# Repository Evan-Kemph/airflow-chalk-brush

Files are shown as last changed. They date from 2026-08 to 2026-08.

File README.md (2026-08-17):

# Airflow Chalk Brush

A handheld, rechargeable brush for cleaning chalk off climbing holds. A small motor and impeller blow air out a nozzle right at the bristles, so loosened chalk gets carried away instead of resettling into the texture of the hold.

Designed to be cheap, easy to assemble, and fully 3D printable apart from a short list of off-the-shelf parts. Everything here is free to use, modify, and remix.

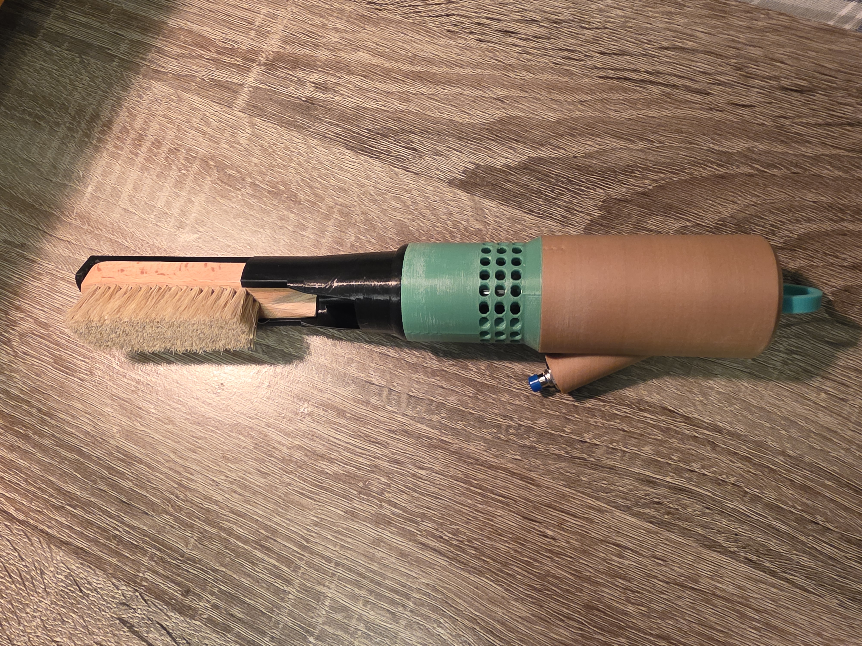
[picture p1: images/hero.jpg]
The finished brush


---

## Contents

- [What it does](#what-it-does)
- [How it works](#how-it-works)
- [Bill of materials](#bill-of-materials)
- [Printed parts](#printed-parts)
- [Print settings](#print-settings)
- [Support placement](#support-placement)
- [Assembly](#assembly)
- [Using it](#using-it)
- [Design notes](#design-notes)
- [Troubleshooting](#troubleshooting)
- [Remixing this design](#remixing-this-design)
- [Safety](#safety)
- [License](#license)

---

## What it does

Brushing a climbing hold knocks chalk loose, but a lot of it just settles back into the surface. This brush adds a burst of air at the bristle line so the chalk you loosen actually leaves the hold.

The body is a threaded tube that stacks from the bottom up:

| Section | Contains |
|---|---|
| **Bottom** | LiPo battery, USB-C charging board, button, integrated carabiner clip |
| **USB board spacer** | Braces the charging board so plugging in a cable can't push it inward |
| **Motor mount** | Holds the motor; routes the motor wires *downward* into the bottom section |
| **Middle (hilt)** | Impeller chamber and air intakes |
| **Head** | Air channel, exit nozzle, and brush mount |

The main sections screw together with printed threads, so the brush fully disassembles for battery access or repair — no glue holding the body together.

One design decision worth explaining: the motor mount sits *between* the bottom and middle sections specifically so the motor's wires exit downward rather than upward. That puts every electrical component — battery, charging board, button, and both motor leads — inside the bottom section, which means **the entire circuit is soldered as one piece with no connectors anywhere.** Fewer parts, nothing to work loose, and nothing to accidentally unplug when you unscrew the brush.

Press and hold the button to run the motor. Release to stop. Charge over USB-C.

---

## How it works

Air is drawn in through intake holes in the middle section, pushed up past the impeller, and forced through a narrowing channel to a nozzle that exits at the base of the bristles.

The interesting engineering problem here is that a small axial fan is a **high-flow, low-pressure** device. It moves a lot of air when the path is open, but it stalls badly against a restriction. Early versions of this design had a nozzle that was too small, and instead of blowing air out the front, the fan simply recirculated it back out the intake holes — a lot of noise and no useful airflow.

The final design solves this by keeping total flow restriction low: a generously sized exit, a smooth gradual taper rather than an abrupt contraction, rounded rather than sharp-edged openings, and a tight impeller tip clearance so air doesn't leak backwards around the blades.

More detail in [Design notes](#design-notes).

---

## Bill of materials

> **Affiliate disclosure: I do not profit from any of these links.** They aren't affiliate links and I receive nothing if you buy through them. They're simply the exact parts I bought, linked so you can match what the model was designed around. Buy them anywhere you like.

| Part | Qty | Notes | Link |
|---|---|---|---|
| Coreless motor, 8520 (8.5 × 20 mm), 3.7 V | 1 | 1 mm shaft. Sold as micro-drone spares, usually in pairs. | https://www.amazon.com/dp/B07CPT5TSL?ref_=ppx_hzsearch_conn_dt_b_fed_asin_title_1 |
| 1S LiPo battery, 3.7 V | 1 | 2100mAh. Must physically fit the bottom section. | https://www.amazon.com/dp/B091YKTT9S?ref=ppx_yo2ov_dt_b_fed_asin_title |
| TP4056 USB-C charging module **with protection** | 1 | Get the 3-chip version (TP4056 + DW01A + FS8205). The 2-chip version has no battery protection. | https://www.amazon.com/dp/B07PKND8KG?ref_=ppx_hzsearch_conn_dt_b_fed_asin_title_3 |
| Momentary pushbutton, 12 mm | 1 | Rated 3 A or better. Panel-mounts through the printed hole. | amazon.com/dp/B07RTZVZ6L?ref_=ppx_hzsearch_conn_dt_b_fed_asin_title_4 |
|switch|1|switch to turn on and off circuit, as to prevent it from turning on in a gym bag|https://www.amazon.com/dp/B09R43HCY3?ref_=ppx_hzsearch_conn_dt_b_fed_asin_title_4&th=1|
| Series resistor | 1 | ~1 ohm. See [Troubleshooting](#troubleshooting) for why this is here. | any |
| Wooden brush head | 1 | Cut flat 20mm below the bottom bristles and make an indent (see photos) | https://www.amazon.com/dp/B08XKM8LL2?ref_=ppx_hzsearch_conn_dt_b_fed_asin_title_2 |
| Silicone wire, 22–24 AWG | — | Short lengths, red and black. | https://www.amazon.com/dp/B07TX6BX47?ref=ppx_yo2ov_dt_b_fed_asin_title&th=1 |
| Heat shrink tubing | — | Assorted small sizes. | — |

**Approximate total cost: cheaper than buying the stupid overpriced one I saw on Instagram**

Most items come in multi-packs, so the per-unit cost is lower if you build more than one.

### Substitutions

The design is not fussy about brands, but a few things do matter:

- **The charging board must have battery protection.** Boards without it will let a LiPo over-discharge, which ruins the cell and is a genuine fire risk.
- **The battery must be a single cell (1S / 3.7 V).** A 2S pack will destroy the motor and is not compatible with this charging board.
- **The motor must be rated for 3.7 V.** Many similar-looking motors are 6 V or 12 V and will barely turn on a 1S cell.

---

## Printed parts

Seven files, six required and one optional. Numbered in assembly order.

| # | File | Qty | Description |
|---|---|---|---|
| 1 | `bottom.stl` | 1 | Battery compartment, USB-C port opening, button hole, integrated carabiner clip |
| 2 | `usb-board-spacer.stl` | 1 | Sits between the bottom and the motor mount. Braces the charging board from behind so plugging in a USB cable can't push it out of position — this removes the need to glue the board in. |
| 3 | `motor-mount.stl` | 1 | Holds the motor. Sits between the bottom and middle sections, with a pass-through for the motor wires to route down into the bottom. |
| 4 | `middle-hilt.stl` | 1 | Impeller chamber and air intakes |
| 5 | `head.stl` | 1 | Air channel, exit nozzle, and brush mount |
| 6 | `switch-clip.stl` | 1 | Retains the button and prevents accidental activation in a bag or on a harness. hold in the switch so it does not fall out of its housing |
| 7 | `carabiner-clip.stl` | 0–1 | **Optional.** Standalone replacement for the carabiner clip already built into the bottom section. If that clip snaps off, glue this one on instead of reprinting the whole bottom. |

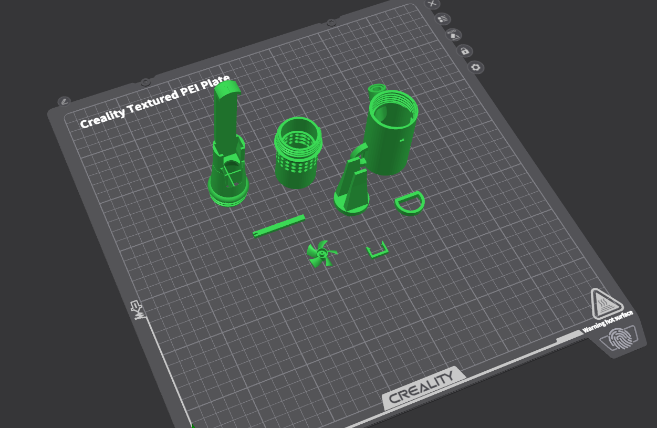
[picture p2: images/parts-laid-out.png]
All printed parts


---

## Print settings

These are what I used. A starting point, not gospel — your printer may want different numbers.

| Setting | Value |
|---|---|
| Material | PLA or Nylon (recommended, but PLA is plenty strong) |
| Layer height | 0.2mm |
| Walls / perimeters | 3 |
| Infill | any (10-15% is fine) |
| Supports | Yes — see below |
| Print orientation | see images |

### Notes on printing threads

The threads are modeled as real geometry (trapezoidal profile, 3 mm pitch, 1.5 mm depth) rather than cosmetic thread features, so they print and function as actual threads.

They're designed with **0.4 mm radial clearance** between the male and female parts. If your printer runs tight and the sections won't thread together, that clearance is the thing to adjust — either scale slightly or reprint from the source CAD with a larger gap. If they thread together loosely and wobble, reduce it.

Trapezoidal threads were chosen over sharp V-threads specifically because they print reliably on FDM: the flat crests and roots don't need fine resolution to come out clean, and they self-align when screwing together.

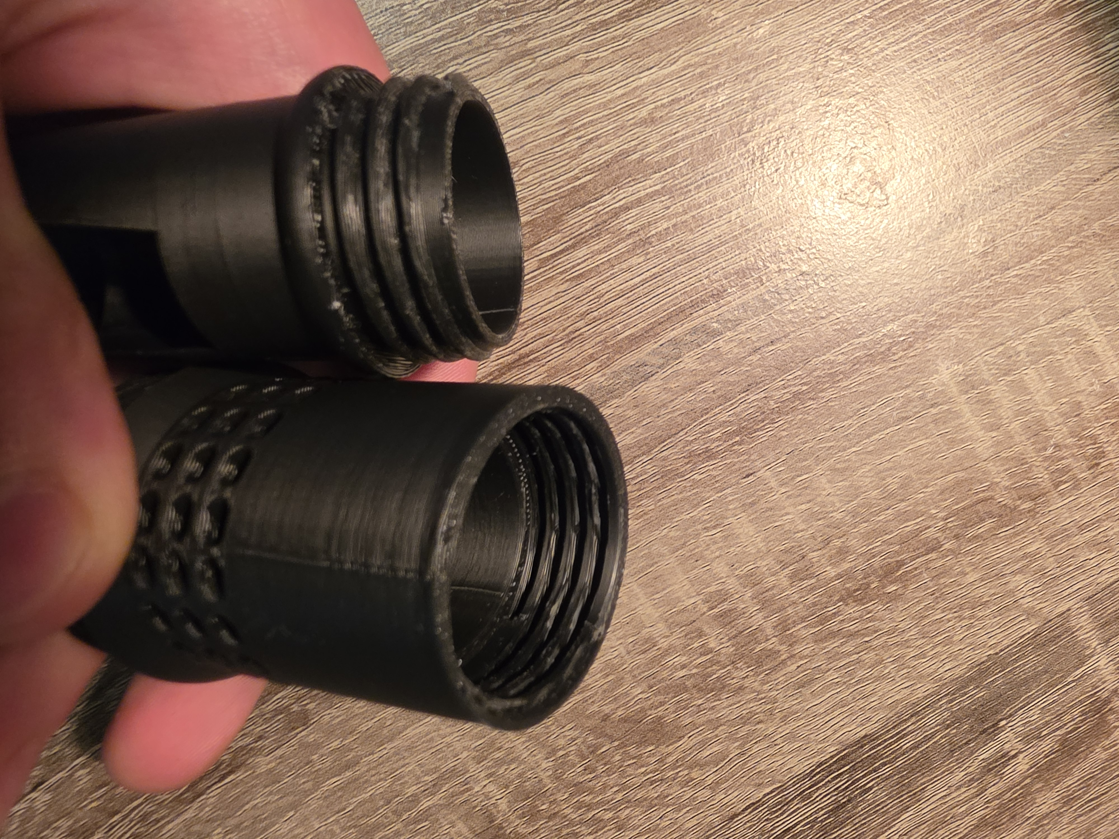
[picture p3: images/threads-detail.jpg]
Printed threads


---

## Support placement

Where I placed supports:

**Bottom**

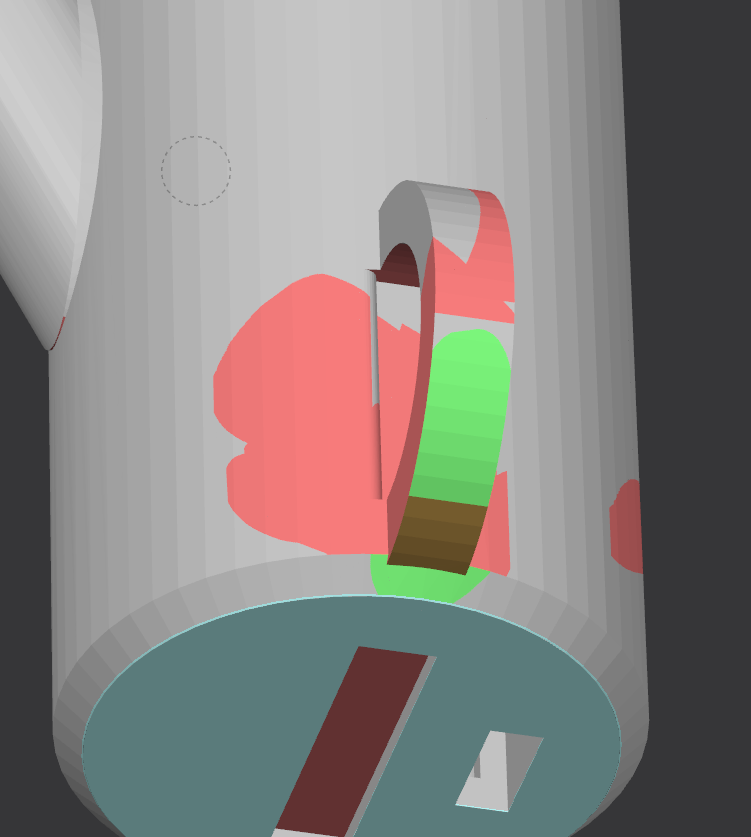
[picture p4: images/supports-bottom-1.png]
Support placement — bottom


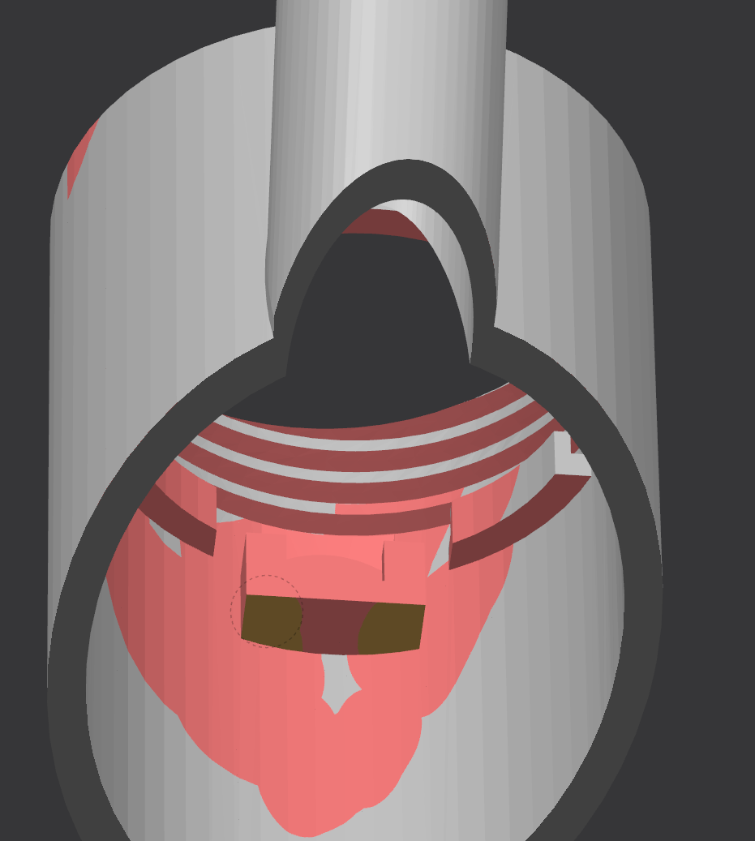
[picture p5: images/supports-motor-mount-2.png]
Support placement — motor mount, second view


**Motor mount**

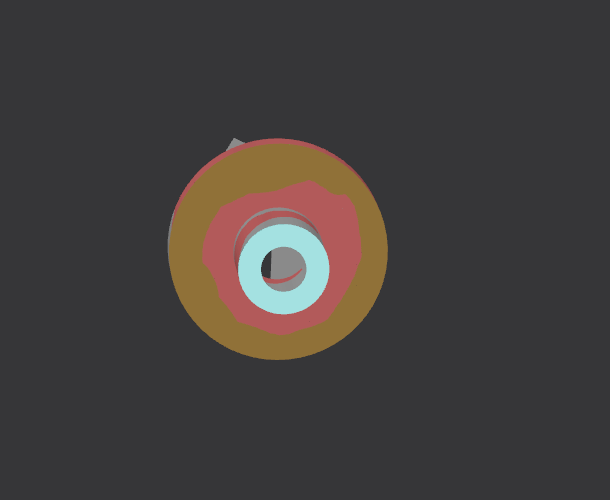
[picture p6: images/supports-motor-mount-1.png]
Support placement — motor mount


**Remaining parts**

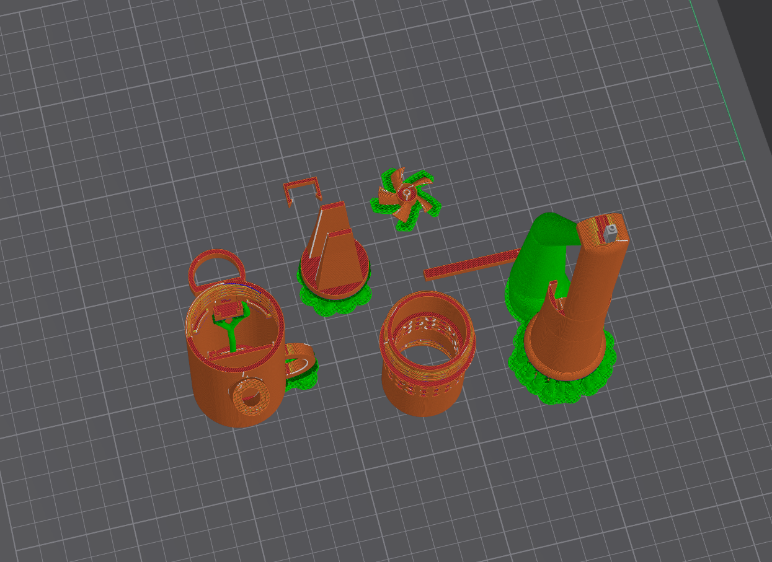
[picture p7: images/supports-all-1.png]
Support placement — remaining parts


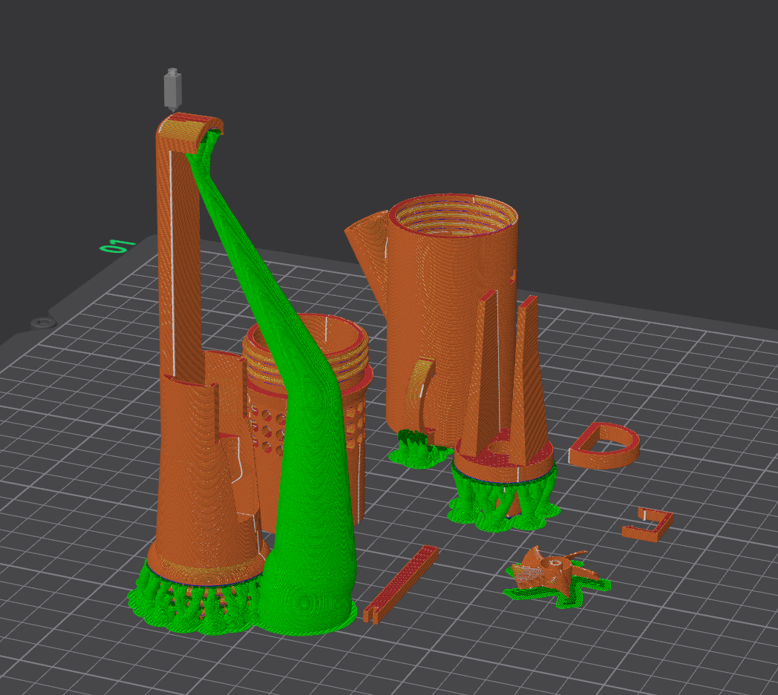
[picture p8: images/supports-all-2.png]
Support placement — remaining parts, second view


ALL supports work best as tree/organic supports
Avoid putting supports on: middle, switch clip, usb board spacer, clip.
Auto supports: head, fan
Custom Supports: bottom, motor mount

---

## Assembly

### 1. Test fit the printed parts

Before adding electronics, screw the bottom, middle, and head sections together and confirm the threads engage smoothly. Clean up any stringing or elephant's foot on the thread starts. If sections bind, chase the threads by screwing them together and apart a few times — printed threads usually loosen up after a few cycles.

Also dry-fit the spacer and motor mount to confirm they seat flat and the wire pass-through lines up.

### 2. Mount the motor

Press the motor into its pocket in `03-motor-mount.stl`. It should be a snug fit; a dab of CA glue will hold it if your print runs loose.

Feed the motor leads **down** through the wire pass-through so they come out on the bottom side of the mount. This is the whole point of this part — every electrical connection ends up in the bottom section, so nothing needs connectors.

**[FILL IN: wire length that works well]**

### 3. Wire the electronics

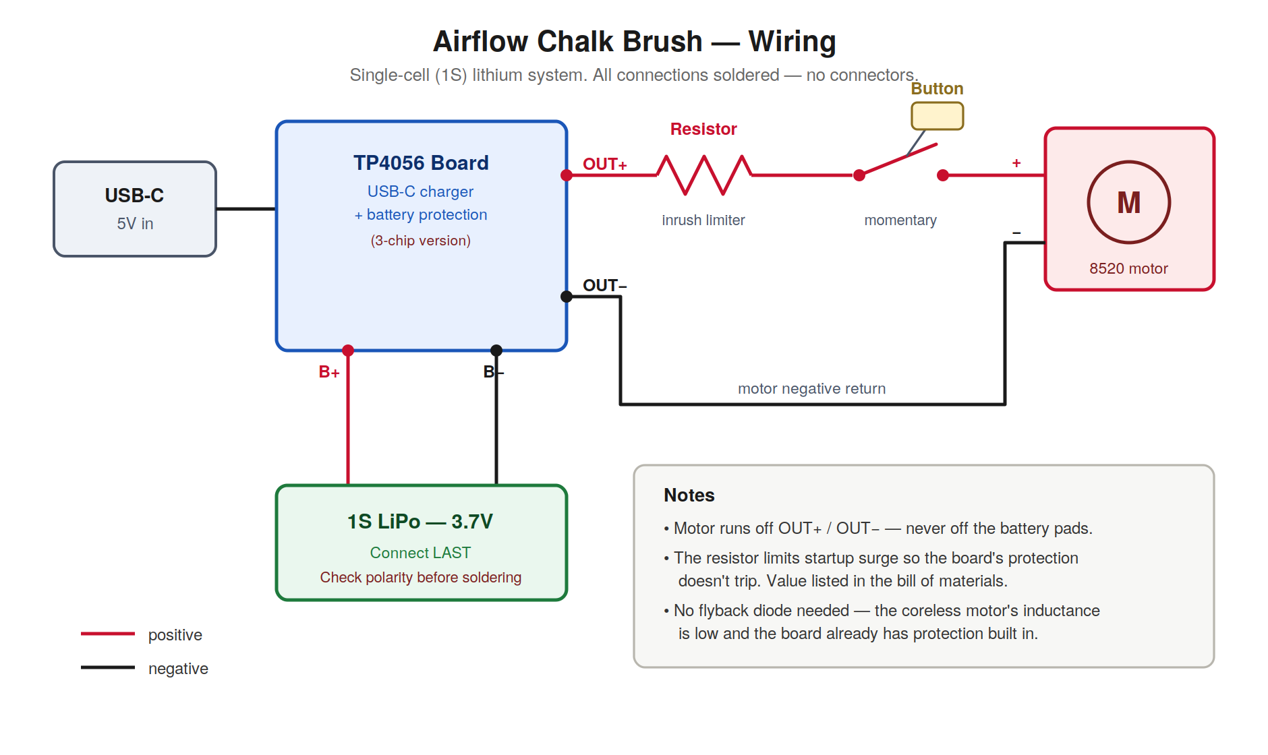
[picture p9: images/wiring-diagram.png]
Wiring diagram


1. Solder the **series resistor** inline on the motor's positive lead. Insulate it with heat shrink.
2. Solder the **button** inline on that same positive lead, between the board's `OUT+` and the resistor.
3. Solder the **motor negative** lead to the board's `OUT−`.
4. **Last**, connect the battery to the board's `B+` and `B−` pads.

> **Wire the battery last, and tape the battery leads while you work.** A 1S LiPo can deliver a very high short-circuit current. Double-check polarity against the board silkscreen before connecting — some cheap batteries ship with reversed connector pinouts.

Test the circuit before anything goes into the housing. It is much easier to fix a bad joint on the bench than inside a tube.

### 4. Install the button and switch clip

Push the button through the hole in the bottom section and secure it with its included nut.

Fit `06-switch-clip.stl` to retain it. The switch clip just fits over the switch in the bottom once the switch is installed to prevent it from slipping out of its housing. The switch keeps the device from activating in your gym bag on accident. 

### 5. Fit the charging board, spacer, and battery

Seat the TP4056 board so the USB-C port lines up with the opening in the bottom section.

Fit `02-usb-board-spacer.stl` behind the board. The spacer takes the insertion force from the USB cable, so the board stays put without glue. Check by plugging a cable in and confirming the board doesn't shift.

Tuck the battery into the bottom compartment. 

### 6. Stack the assembly

BE CAREFUL NOT TO SQUISH THE WIRES WHEN SCREWING THE BOTTOM INTO THE MIDDLE!!!!!!

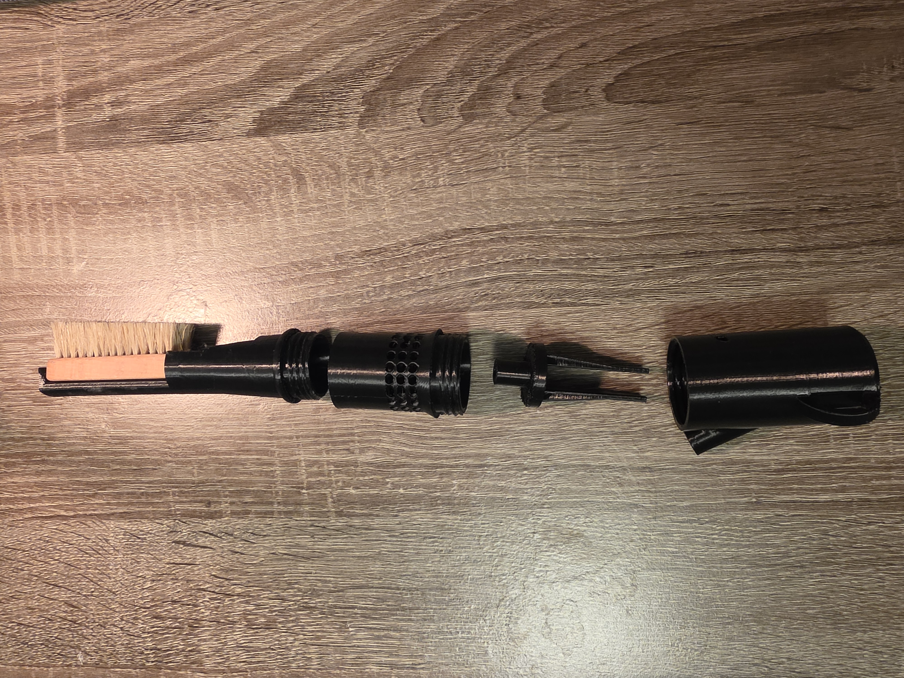
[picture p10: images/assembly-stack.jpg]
Assembly stack


Working from the bottom up:

1. **Bottom** — battery, board, spacer, button, switch clip, and all soldered connections
2. **Motor mount** — motor installed, wires routed down into the bottom, motor mount hugs the battery and sits on the walls around the battery
3. **Middle (hilt)** — screws onto the bottom, capturing the motor mount in the stack
4. **Head** — screws onto the middle

### 7. Fit the impeller

Press the propeller onto the motor shaft. The more open side of the propeller (fan) should be facing upward, see the images, but its the same orientation as on the build plate)

Spin it by hand and confirm it turns freely without touching the chamber walls.

### 8. Attach the brush head

Once the brush head is cut and fits, just bend the top of the head slightly (careful not to break it off) and slide the brush into the head.

### 9. Final test

Assemble fully, press the button, and confirm the motor spins up and air comes out the nozzle.

### Optional: spare carabiner clip

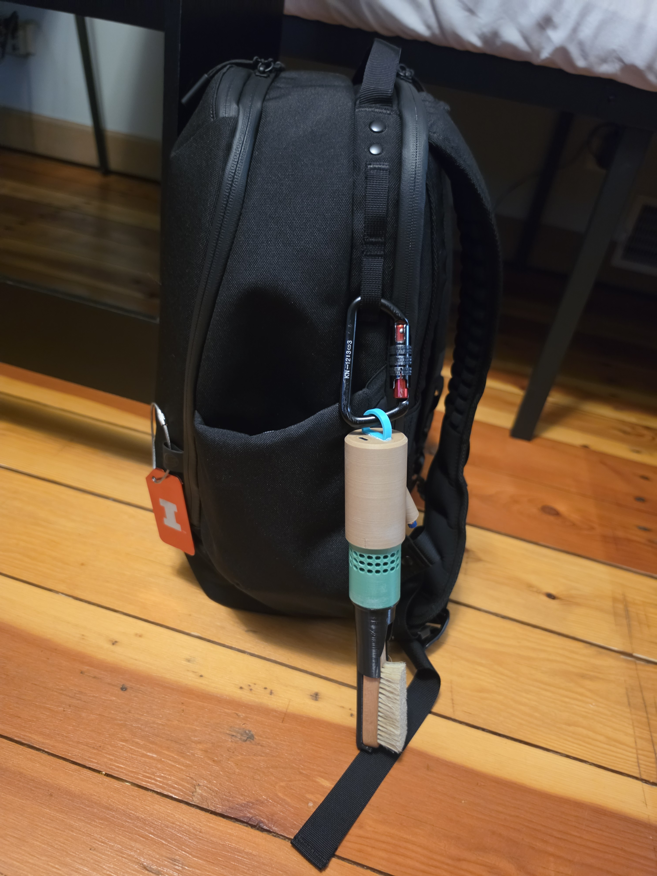
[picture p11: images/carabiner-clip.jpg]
Carabiner clip


`07-carabiner-clip.stl` is only needed if the clip built into the bottom section breaks. If that happens, remove what's left of the original and glue this one on — no need to reprint the entire bottom section.

Use any CA glue (and activator for best application) to glue in the carabiner clip to the bottom of the assembly.
---

## Using it

- Hold the button to run the motor. Use short bursts or an extended press while brushing the hold or after brushing to loosen the chalk — a few seconds is plenty for a hold.
- Brush the hold as normal; the airflow clears the chalk you loosen.
- Charge over USB-C. The charging board's LED indicates charge state (typically red charging, blue/green full).
- **Don't run the motor while charging.** The board detects a full charge by sensing current draw, and a load on the output confuses that detection, so it may never terminate the charge properly.

Runtime is effectively unlimited for normal use — at burst usage you'll go weeks between charges.

---

## Design notes

For anyone wanting to understand *why* it's built this way, or planning to modify it. Also an honest record of what didn't work.

### The airflow problem

The core difficulty is that **an axial fan (a propeller) produces high flow but very little pressure.** A small coreless motor spinning a propeller might produce on the order of 50–150 Pa. Forcing air through a narrow nozzle at high velocity needs several hundred Pa or more.

When you connect a low-pressure fan to a high-resistance nozzle, the fan stalls: it can't push air forward, so air recirculates around the blade tips and escapes back out the intake. The device gets loud and does nothing. This is exactly what the first several revisions did.

What helped, roughly in order of impact:

1. **A larger exit opening.** By far the biggest factor. Small nozzles feel intuitively right (fast jet!) but are the direct cause of stall with this class of fan.
2. **A smooth, gradual taper into the exit.** An abrupt contraction causes large pressure losses; a gentle cone recovers a lot of that.
3. **Rounded rather than sharp-edged openings.** A sharp edge makes the flow separate, which shrinks the working area below the hole's physical area.
4. **Tight impeller tip clearance.** Air leaking over the blade tips from the high-pressure side back to the low-pressure side directly reduces achievable pressure. Aim for roughly 0.3–0.5 mm total.
5. **Keeping the intake generous.** Restricting the intake to "balance" it against the exit is counterproductive — it adds restriction to the side that wasn't the problem.

### What I tried that didn't work

- **A 5015 centrifugal blower.** Centrifugal blowers make far more static pressure than axial fans and would be the technically correct choice for a narrow, high-velocity nozzle. But most 5015 units sold are 12 V or 24 V, and a 12 V blower on a 3.7 V cell barely turns. Running one properly would need a boost converter, which adds complexity this design was trying to avoid. **If you want to remix toward a centrifugal design, get a genuinely 5 V-rated blower and verify the rating before modeling a housing around it.**
- **Stator vanes.** Straightening vanes downstream of the propeller should recover swirl energy as pressure, and they work in principle — but they're sensitive to angle and spacing, and my attempts didn't produce a measurable improvement. Opening up the flow path was far more effective for far less effort.
- **A capacitor for inrush suppression.** See [Troubleshooting](#troubleshooting).

The jet deflection issue was essentially that the air was swirling inside the head before exiting, causing it to exit at a non-optimal angle. The fins inside force the air to come out straight.

### Thread design

Threads are trapezoidal, swept along a helix as real geometry:

| Joint | Major diameter | Pitch | Depth | Clearance |
|---|---|---|---|---|
| Bottom ↔ Middle | 35 mm | 3 mm | 1.5 mm | 0.4 mm radial |
| Middle ↔ Head | 30 mm | 3 mm | 1.5 mm | 0.4 mm radial |

Both use right-handed threads with about 3 turns of engagement, plus a 1 mm chamfer at each thread start so the sections are easy to begin threading.

Threads deliberately stop short of the end of each section rather than running all the way out. That runout zone prevents the fragile overhanging partial thread you get otherwise, and it's how real fasteners are made.

---

## Troubleshooting

### The motor blips on for an instant and stops

The protection circuit is tripping on inrush current. A motor starting from a standstill briefly draws far more current than it does while running, and the protection chip reads that surge as a short circuit and latches the output off.

The fix here is a **small series resistor** on the motor's positive lead, limiting the startup surge enough to stay under the protection threshold. It costs a little motor speed (roughly 10–20%) — not enough to matter for blowing chalk.

A large capacitor across the motor is the more elegant fix in theory, but it only works if the capacitor sits *directly* at the motor terminals. With any meaningful wire length in between, the wiring's inductance lets the fast edge of the surge through before the capacitor can respond. In this build that location wasn't practical, so the resistor is the better real-world answer.

### Air comes out of the intake holes instead of the nozzle

The fan is stalling against too much restriction. See [Design notes](#design-notes). Enlarge and smooth the exit — don't shrink the intake.

### The sections won't thread together

Printed thread clearance is too tight for your printer. Run the threads together a few times to wear them in, clean up stringing on the thread starts, or reprint from the source CAD with more clearance.

### The motor doesn't spin at all

Check battery polarity at the board, confirm the battery has charge, and confirm you have the protected (3-chip) board with the motor wired to `OUT+`/`OUT−` rather than directly to the battery pads.

---

## Remixing this design

**[FILL IN: public Onshape document link]**

The full parametric CAD is shared publicly, not just the STLs. If you want to change a dimension — battery size, brush mount, nozzle diameter, thread clearance — editing the source model is far easier than modifying a mesh.

To use it: open the link, then **Make a copy** into your own Onshape account (a free hobbyist account works). From there everything is editable.

Modifications that would be genuinely useful:

- A version sized around a different battery or brush head
- A centrifugal version using a verified 5 V blower
- A version with heat-set inserts instead of printed threads
- A nozzle variant tuned for a different balance of flow versus velocity

If you build one or improve it, I'd love to see it.

---

## Safety

**Lithium batteries deserve respect.** This project uses a bare LiPo cell inside an enclosed printed housing.

- Use a charging board **with built-in protection**. Over-discharging a LiPo can ruin the cell or start a fire.
- Never puncture, crush, or sharply bend the cell. Take care when closing the housing that no wire or printed edge presses into it.
- Don't charge unattended, and don't charge a cell that's swollen, hot, or physically damaged.
- Check polarity before connecting the battery. Reverse polarity can destroy the board and damage the cell.
- Don't run the motor while charging.
- Keep fingers away from the impeller while it's spinning, and don't run it with the head removed.

This design is shared as-is with no warranty. You're responsible for building and using it safely.

---

## License

This work is licensed under [CC BY-SA 4.0](https://creativecommons.org/licenses/by-sa/4.0/). You may share and adapt it, including commercially, provided you give credit and license derivatives under the same terms.

---

## Acknowledgements

**[FILL IN: brush manufacturer, any prop/impeller design you used or adapted, and anyone who helped or tested it. If you used someone else's model, credit them here and confirm their license permits it.]**

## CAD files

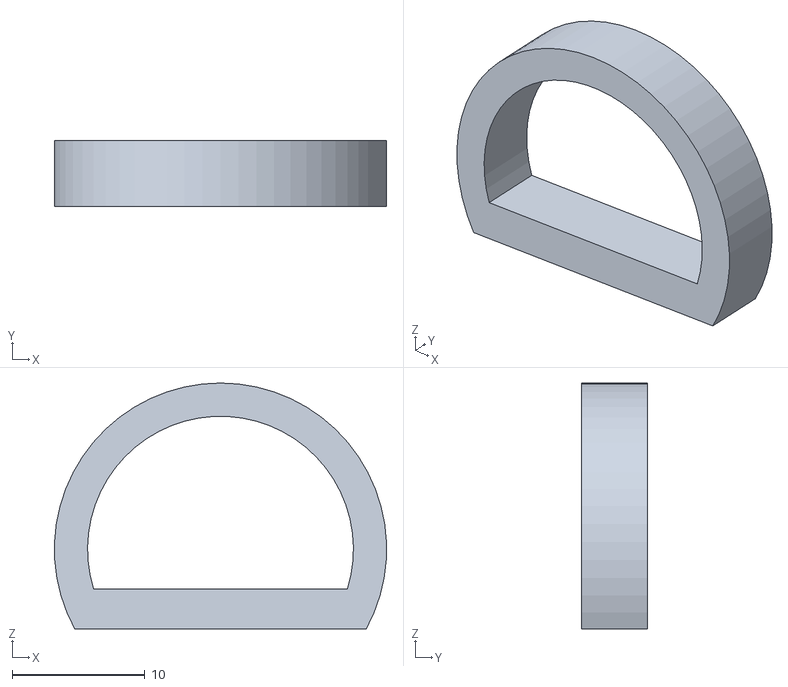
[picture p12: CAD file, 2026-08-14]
stl/carabiner_clip.stl
25.0 x 5.00 x 18.5

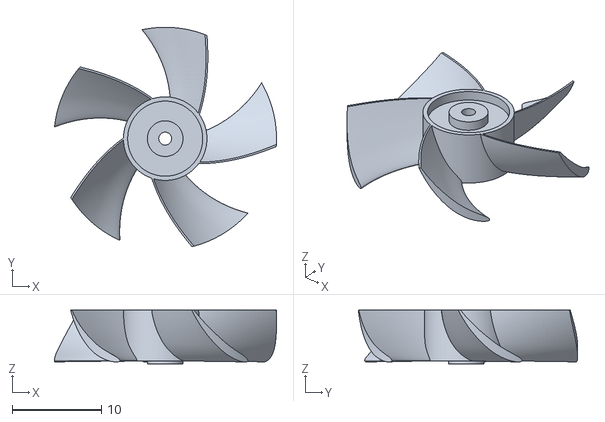
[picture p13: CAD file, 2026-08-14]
stl/fan.stl
24.9 x 24.6 x 6.00

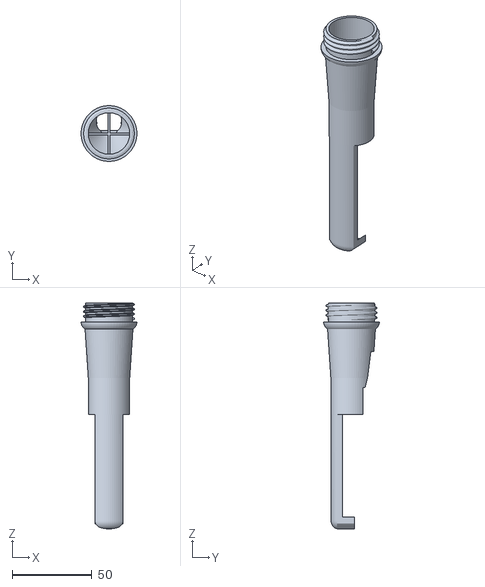
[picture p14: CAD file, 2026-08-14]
stl/head.stl
35.0 x 34.9 x 141.8

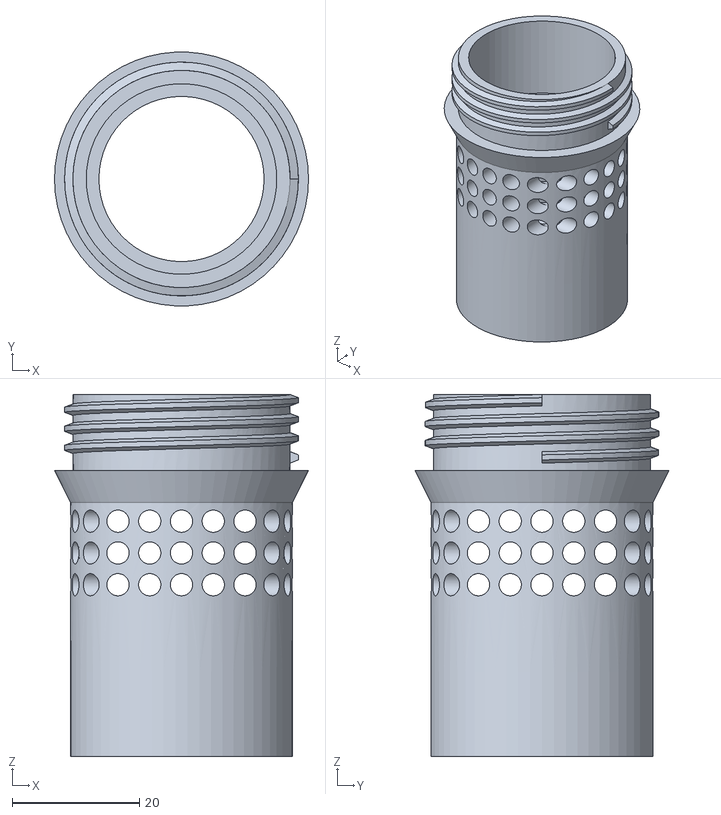
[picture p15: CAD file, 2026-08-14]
stl/middle_hilt.stl
40.0 x 39.9 x 57.0

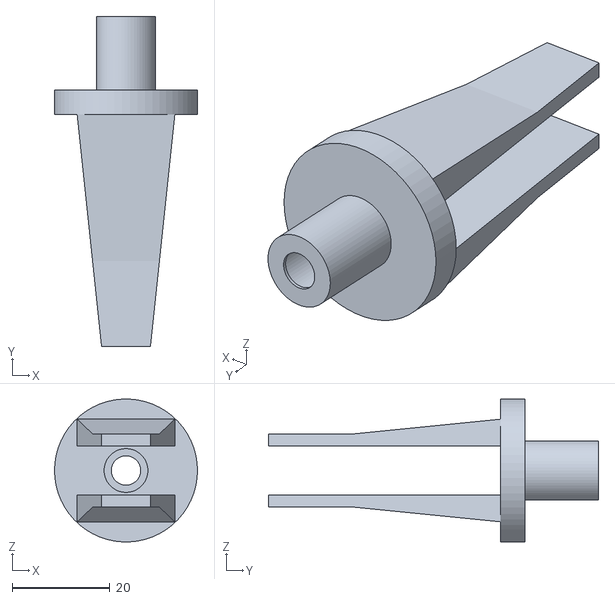
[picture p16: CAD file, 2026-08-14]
stl/motor_mount.stl
29.2 x 67.5 x 29.2

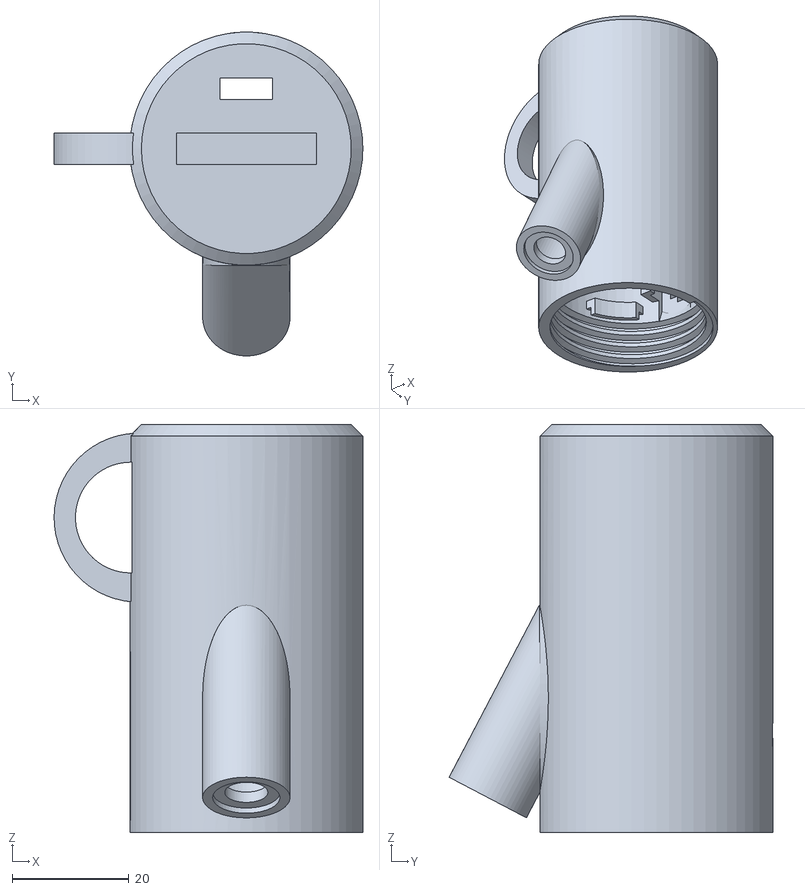
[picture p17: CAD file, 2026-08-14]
stl/Bottom.stl
53.0 x 55.6 x 70.0

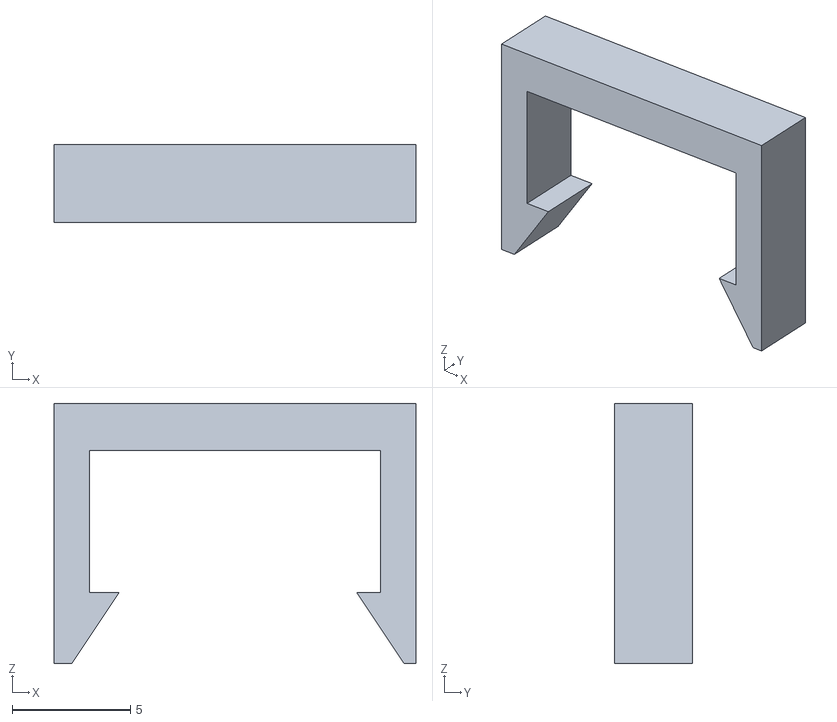
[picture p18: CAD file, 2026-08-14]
stl/switch_clip.stl
15.3 x 3.30 x 11.0

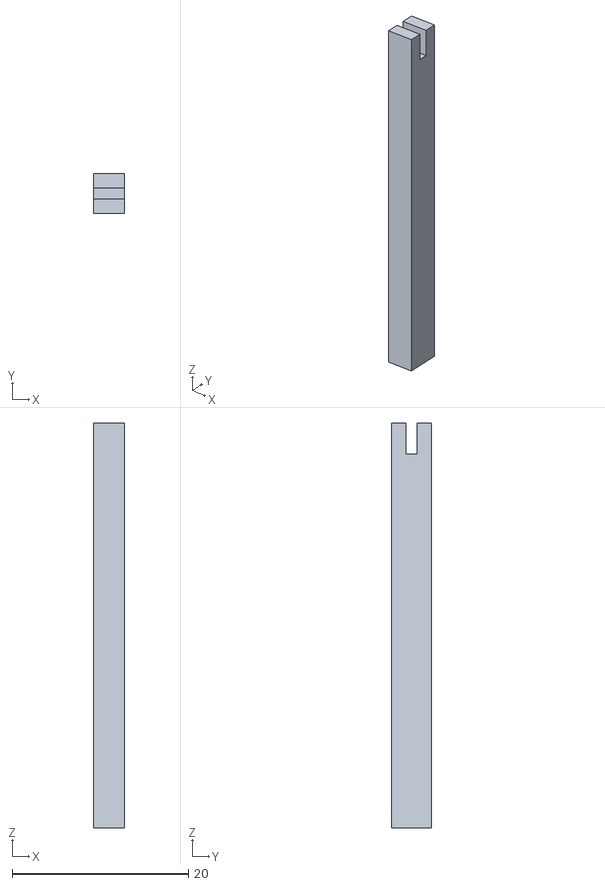
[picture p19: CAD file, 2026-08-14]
stl/usb_board_spacer.stl
3.50 x 4.50 x 46.0

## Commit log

2026-08-14 Initial upload.
    [Bottom.stl, carabiner_clip.stl, fan.stl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]
2026-08-14 Revise README with updated parts and print settings
    Updated the parts list with links and additional details. Modified print settings and file names for clarity.
2026-08-14 Revise battery specs and improve assembly instructions
    Updated specifications for the 1S LiPo battery and switch clip installation details. Added support placement notes and clarified assembly instructions.
2026-08-14 Update README with printing and assembly details
    Clarified infill percentage and provided additional details on motor mount installation and brush head fitting.
2026-08-17 Add switch to components list for circuit control
    Added a switch to the components list to control circuit power.
